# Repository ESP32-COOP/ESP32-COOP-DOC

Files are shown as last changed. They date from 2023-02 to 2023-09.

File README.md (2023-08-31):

<div align="center">
logo JS-BLE-DOC

# [ :book: ESP32 Coop Door Documentation ](https://coop-door.vercel.app/) 

The goal is to document the setup & configuration of the [esp32-coop](https://github.com/ESP32-COOP) project as well as the protocol in which the two devices communicate over BLE 
</div>

# :memo: Summary:

- [:page_facing_up: **Project Overview**](page_facing_up-project-overview): quick presentation of the mother project (goal, link device, protocol used, problematic) 
- [:iphone: **The App**](#iphone-app-installation): how to get the it
- [:toolbox: **Build instruction**](#toolbox-build-instruction)
   - :clipboard: Requirement
   - :flashlight: Wiring
   - :rocket: First Boot
   - :house: 3D file 
- :signal_strength: **Communication protocol**
   - :electric_plug: Run-down on how BLE works 
   - :bar_chart: The type of data required by the project (in progress) 
   - :computer: Code snippet for each characteristic (in progress)

# :page_facing_up: Project Overview

plan

The [COOP-DOOR](https://github.com/ESP32-COOP) project aims to create an intelligent and user-friendly automatic coop door system. It empowers users to customize the door's behavior based on specific conditions, such as time and light levels. To facilitate device management and monitoring, the project offers a mobile app. 

The app enables users to track device and sensor health, as well as configure various operating conditions. For a demonstration of the project, please refer to the demo [here](https://github.com/ESP32-COOP/ESP32-COOP-DOOR-WEB). The core of the smart coop door relies on the ESP-32 platform, and the code repository can be found [here](https://github.com/ESP32-COOP/ESP32-COOP-DOOR-CORE). 

This documentation page aims to guide users through the setup process, hardware requirements, and detailed workings of the system.

<br clear="left"/>

# :iphone: App Installation

app icon
<br clear="right"/>
The coop door application is a Progressive Web App, meaning it functions as a website and can be installed on mobile devices for offline usage.
<br clear="left"/>
<br clear="left"/>

To install the app, follow these steps:

1. Visit [coop-door.vercel.app](https://coop-door.vercel.app) using your mobile device's web browser.
2. A small popup will prompt you to install the app. Tap "Install" to proceed.
3. Alternatively, if the popup doesn't appear, you can manually add the app to your home screen by:
   - Tapping the three dots in Chrome.
   - Scrolling down and selecting "Add shortcut to home screen" or "Install app."
4. The app will be installed on your device and accessible from the home screen.

Now, you can conveniently use the mobile app to monitor and control your coop door system, even without an internet connection.

# :toolbox: Build instruction

Look out for instruction variations depending on the version of the project you're building.

First of all, you will need to flash the firmware on the ESP32. Please refer to the instructions [here](https://github.com/ESP32-COOP/ESP32-COOP-DOOR-CORE). I do recommend unplugging the motor before flashing the firmware to avoid any connection problems caused by the encoder or any accidental movement of the powered motor.

## :clipboard: Requirement

This projet use :<br>
- a ESP32 [WEMOS lolin32 lite](https://fr.aliexpress.com/item/4000038780903.html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) ( can be any esp32 with BLE), <br>
- a H-Bridge [l298n](https://fr.aliexpress.com/item/1005004510885871.html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),<br> 
- a [motor with a encoder](https://fr.aliexpress.com/item/4001314473291.html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), <br>
- and a [photoresistor](Vhttps://fr.aliexpress.com/item/32760631393.html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)

Additionally, you'll need some basic items such as wires, soldering equipment (or soldering iron), and a 3D printer or woodworking tools, depending on your preferences.

Please note that you can easily swap out any component of this project for a similar one. It will most likely work out fine, but it may require some extra work. I would recommend it only to experienced thinkers.

## :electric_plug: Wiring
As illustrated below, follow these connections:

ESP32:
- Connect encoder signal to pin 2 (yellow) and pin 15 (green).
- Attach a resistor to pin 34 for analog value.
- Control the H-bridge with pins 27 (ENA), 26 (IN1), and 15 (IN2).

Remember to establish a ground connection between the H-bridge and the ESP32.

wiring diagram

## :rocket: Initial Setup

**Before Coop Installation:**

It's a good idea to run comprehensive tests before installing the device in the coop. Debugging is much easier and less frustrating when you're comfortably situated in a well-ventilated room.

**Initial ESP32 Boot:**

When the ESP32 boots up initially, it assumes the door is closed. If that's not the case, unplug either the motor or the ESP and manually close the door.

**Proper Device Boot:**

Now you can properly start up your device. Inside the app, go to settings and then to the door section. Set the number of rotations you want the motor to perform in order to open the door. Click the test button, and the motor will complete a full cycle (going up and then back down). Begin with a small rotation number, and gradually adjust it until you reach your desired door height.

**Optimal Rotation Value:**

Once you've figured out the best number of motor rotations, jot down this value along with the light sensor reading. To sync the ESP32's time, head to the app's home page and click on the time badge. A panel will appear, showing the time difference between your phone and the ESP32, along with a sync button.

**Setting Conditions:**

With that sorted, configure open and closing conditions in the door settings. Base these conditions solely on time, and set the door to stay open for the rest of the day.

**Chicken Entry Time:**

Return to the coop at the designated chicken entry time to check the light sensor value. If needed, adjust the closing condition within the app's settings.

**Autonomous Operation:**

To enable autonomous operation, revisit the settings and door page. Click on 'auto' and then 'apply'.

## :carpentry_saw: Casing Details

You can find the 3D model at this [link](https://github.com/ESP32-COOP/JS-BLE-DOC/blob/main/3D_file_esp32_coop.stl), and the technical drawing is available //todo.

# :signal_strength: Wireless comunication
## :loudspeaker: BLE Protocol

BLE illustration
<br clear="right"/>
To better understand the following, you must understand the basics of the Bluetooth Low Energy (BLE) protocol.<br/>
The key part to understand is that it uses a fixed-size array of bytes to send data to an endpoint.
<br clear="left"/>
<br clear="left"/>

Each endpoint can have three properties: writable, readable, and notifyable.

- Writable: It allows the external user to write/edit the endpoint (officially called characteristic in BLE).
- Readable: It allows reading the characteristic's value.
- Notifyable: It allows getting notified when that value is updated.

A byte is made out of 8 bits, and its value can go from 0 to 255.

To send the desired value in bytes, you must think it through:

- You will need to figure out the array size you will need and the function to convert it back and forth in C and in JS.

Currently, there are five communication subjects:
1. The light sensor (made out of 4 bytes).
2. The time (made out of 9 bytes, 8 to represent UNIX time and 1 to represent the UTC offset).
3. The closing condition
4. The opening condition
5. Door settings

## :bulb: Data size

With BLE the goal is to send the smallest array posible

for each communication subjects i will justify each bytes and explain it's encoding

1. **The light sensor** produces 4 bytes of data. Our objective is to transmit the current value, along with the minimum and maximum values recorded by the sensor. To achieve this, we need an additional variable called a "divider." The maximum sensor value is fixed at 1024, while the highest value representable by a byte is 255.

   Calculating the divider is straightforward: we divide the maximum sensor value of 1024 by 255. This gives us the scaling factor needed for our encoding.

   With the divider in hand, we can create an encoded transmission as follows:
   - Current Value: current_value / divider
   - Minimum Value: min_value / divider
   - Maximum Value: max_value / divider
   - Unused Placeholder: (for the divider value)

   Reverting back to the original values is easy: simply multiply by the divider. This process maintains the integrity of the data throughout the encoding and decoding stages.
2. **The time** use 9 bytes The initial 8 bytes encode the UNIX time, while the ninth byte stores the user's country time offset.
   
   **Encoding UNIX Time**:
   To encode the UNIX time:
   - Begin by taking the lowest 8 bits of the time value using a bitwise AND operation with 0xff.
   - Place this extracted value in the current byte of the array.
   - Divide the time value by 256 to discard the lowest 8 bits for the next step.
   
   **Decoding UNIX Time**:
   To decode the UNIX time:
   - Set up a variable to hold the decoded time value.
   - Iterate eight times (for each byte), starting from the most significant byte down to the least:
       - Multiply the current result by 256 (shift left by 8 bits) to make room for the next byte.
       - Add the value of the current byte to the result.
   
   **Encoding Time Offset**:
   Encoding the time offset is simple. You subtract the time offset from 12 and then add back 12 during decoding. This process is necessary because the time offset ranges from -12 to 12.

3. **Door Condition** use 4 bytes, used by both open condtion and closing condtion.
      We ne the following value: the door mode (checking for light or time), the threshold and finaly the time
      The array is form like this [door_mode, light_treshold / 4, time hour, time minutes]
      The door mode is represented by a single digit, reflecting various modes:
      - 0 : do nothing
      - 1 : change on light condition
      - 2 : change on time condition
      - 3 : change on light and time condition
      - 4 : change on light or time condition
   By adopting this array format and the corresponding door modes, we efficiently handle door conditions during both opening and closing situations.
4. **Door settings** use 2 bytes, with the following needed value the door mode and the number of turn.
   
   The door mode can take on various values:
   - 0: Door closed
   - 1: Door open
   - 2: Test door (opens and closes immediately)
   - 10: Automatic mode with the door closed
   - 11: Automatic mode with the door open
   
   **Number of Turns Encoding**:
   To encode the number of turns, we simply multiply the value by 10.
   
   Here's the array structure for encoding: [door_mode, number_of_turns * 10].

## :gear: Code Snippette
Certainly, here's your code snippet presented in a more readable manner:

## Encoding and Decoding Long Numbers to Bytes

Here, we present functions for encoding and decoding long numbers into bytes. These functions are particularly relevant for working with the UNIX time standard. We provide the code snippets for both C and JavaScript:

### C Implementation

```c
byte* getBytesFromLong(long x) {
  byte* bytes = new byte[8];
  for (int i = 0; i < 8; i++) {
    bytes[i] = x & 0xff;
    x = (x - bytes[i]) / 256;
  }
  return bytes;
}

long getLongFromBytes(const byte* bytes) {
  long result = 0;
  for (int i = 7; i >= 0; i--) {
    result = (result * 256) + bytes[i];
  }
  return result;
}
```

### JavaScript Implementation

```javascript
export function getLongFromBytesBuffer(bytes) {
  let result = 0;
  for (let i = 7; i >= 0; i--) {
    result = result * 256 + bytes.getUint8(i);
  }
  return result;
}

export function getArrayFromBuffer(bytes, len) {
  let result = [];
  for (let i = 0; i < len; i++) {
    result.push(bytes.getUint8(i));
  }
  return result;
}
```

These functions offer efficient ways to convert long numbers to byte arrays and vice versa, which is particularly useful for working with the UNIX time standard. The C and JavaScript implementations cater to different programming environments, ensuring flexibility in usage.

## Tutorial
Here is a video that explain how the BLE work
//todo
Communication between JS and an ESP32

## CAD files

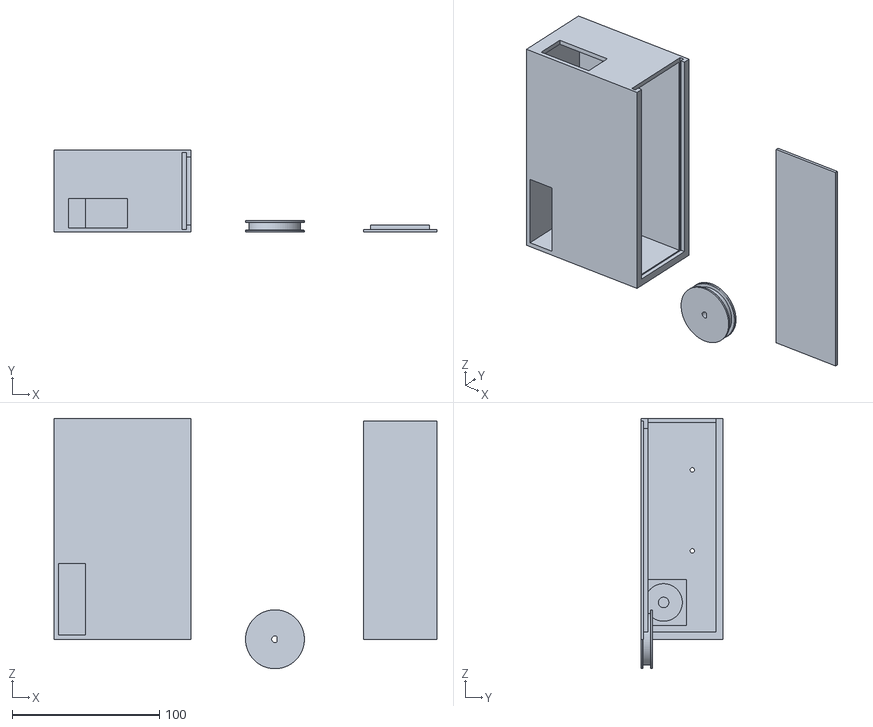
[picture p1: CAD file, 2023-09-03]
3D_file_esp32_coop.Stl
260.0 x 56.0 x 170.0

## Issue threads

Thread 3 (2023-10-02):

Add doc step by step illustration

Qypol342, 2023-10-02:
### Description:
The current documentation for this project is comprehensive but could benefit from step-by-step illustrations to enhance user-friendliness. We need to include the following illustrations to guide users effectively:

### Steps:

-  Set the door to the closed position.
- Power/plug in the device.
-  Open the app on your phone.
-  Finally, upload your settings.

### Illustrations Style:

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

### Comments:
You can request access to the Figma project by commenting on this issue.

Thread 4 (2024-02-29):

Esp32 ble

Peteroooooo, 2024-02-29:
I can't get the esp32 to turn on ble.
What do I exactly have to install on it?

raleighvanepps, 2024-03-09:
if your esp32 is turning on but it's not broadcasting bluetooth, make sure you've flashed it correctly and are supply sufficient voltage. If the input voltage isn't high enough the esp light will turn on but it won't work correctly.

Peteroooooo, 2024-03-12:
I checken

> if your esp32 is turning on but it's not broadcasting bluetooth, make sure you've flashed it correctly and are supply sufficient voltage. If the input voltage isn't high enough the esp light will turn on but it won't work correctly.

I checked the voltage and it seems to be ok.
Is it possible that I load the wrong firmware?

loan-mgt, 2025-03-03:
Flash it again, and you would be certain (could also be a defective exp32).

Open back up the issue if it persists

Closed 2025-03-03.

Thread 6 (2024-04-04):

Motor Control Issue

helidave, 2024-04-04:
Hi.  Firstly thank you for posting this project.
I do not currently have a motor with embedded encoder but I can connect the encoder I do have to the motor shaft and read the rotation.  However when I try to operate the motor from the app it does try to turn the motor (maybe 1/10th of a turn) and always in the same direction.   I do not see a change in encoder value when I look at the ESP serial output.
Any pointers as to what I am doing incorrectly?
Thanks,
David

helidave, 2024-04-07:
please close above thread. I worked out what my problem was. I needed pull up resistors on the signal lines of my encoder.

JohnMcLear, 2024-06-08:
@helidave you can close this yourself.

Closed 2025-03-03.

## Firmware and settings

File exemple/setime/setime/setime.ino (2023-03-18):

#include <ArduinoBLE.h>
#include <ESP32Time.h>

ESP32Time rtc;
//ESP32Time rtc(3600);  // offset in seconds GMT+1

BLEService service("1ce76320-2d32-41af-b4c4-46836ea7a62a"); // Bluetooth® Low Energy LED Service
BLECharacteristic dateCharacteristic("ad804469-19ec-406a-b949-31ae17e43813", BLERead | BLENotify | BLEWrite, 8);
BLECharacteristic lightCharacteristic("947aad02-c25d-11ed-afa1-0242ac120002", BLERead | BLENotify | BLEWrite , 4);
BLECharacteristic doorCharacteristic("c3773399-b755-4e30-9160-bed203fae718", BLERead | BLENotify | BLEWrite , 2);
BLECharacteristic doorCloseCharacteristic("e011ba0e-84c5-4e83-8648-f3e2660c44b0", BLERead | BLENotify | BLEWrite , 4);
BLECharacteristic doorOpenCharacteristic("cc959fff-4f84-4d08-a720-9d9156a48ed5", BLERead | BLENotify | BLEWrite , 4);

//badge
uint8_t ble_value = 0x0;
int analogValue = 500;
int minValue = analogValue; 
int maxValue = analogValue; 

//settings door
int doorWantedStatus = 0;
int doorNbTurn = 1;

//settings close
int doorCloseMode = 0;
int doorCloseLightThreshold = -1;
int doorCloseTimeH = -1;
int doorCloseTImeM = -1;

//settings open
int doorOpenMode = 0;
int doorOpenLightThreshold = -1;
int doorOpenTimeH = -1;
int doorOpenTImeM = -1;


void setup() {
  Serial.begin(9600);
  rtc.setTime(1609459200);
  while (!Serial);

  // begin initialization
  if (!BLE.begin()) {
    Serial.println("starting Bluetooth® Low Energy module failed!");
    while (1);
  }

  // set advertised local name and service UUID:
  BLE.setLocalName("COOP-DOOR");
  BLE.setAdvertisedService(service);
  service.addCharacteristic(dateCharacteristic);
  service.addCharacteristic(lightCharacteristic);
  service.addCharacteristic(doorCharacteristic);
  service.addCharacteristic(doorCloseCharacteristic);
  service.addCharacteristic(doorOpenCharacteristic);
  BLE.addService(service);
  dateCharacteristic.writeValue(0);
  lightCharacteristic.writeValue(0);
  doorCharacteristic.writeValue(0);


  // start advertising
  BLE.advertise();

  Serial.println("BLE LED Peripheral");
}

void loop() {
  // listen for Bluetooth® Low Energy peripherals to connect:
  BLEDevice central = BLE.central();

  // if a central is connected to peripheral:
  if (central) {
    Serial.print("Connected to central: ");
    // print the central's MAC address:
    Serial.println(central.address());

    // while the central is still connected to peripheral:
    while (central.connected()) {
      // if the remote device wrote to the characteristic,
      // use the value to control the LED:
      delay(500);

      manageDate();
      manageLight();
      manageSettingsDoor();
      manageSettingsClose();
      manageSettingsOpen();



    }

    // when the central disconnects, print it out:
    Serial.print(F("Disconnected from central: "));
    Serial.println(central.address());
  }





}

void manageSettingsOpen(){
  if (doorOpenCharacteristic.written() ) {
    Serial.println("update Door Open settings");
    Serial.print(doorOpenCharacteristic.value()[0]);
    Serial.print(";");
    Serial.print(doorOpenCharacteristic.value()[1]);
    Serial.print(";");
    Serial.print(doorOpenCharacteristic.value()[2]);
    Serial.print(";");
    Serial.println(doorOpenCharacteristic.value()[3]);
    doorOpenMode = doorOpenCharacteristic.value()[0];
    doorOpenLightThreshold = doorOpenCharacteristic.value()[1];
    doorOpenTimeH = doorOpenCharacteristic.value()[2];
    doorOpenTImeM = doorOpenCharacteristic.value()[3];
    
  }else{
    //todo
  }
}

void manageSettingsClose(){
  if (doorCloseCharacteristic.written() ) {
    Serial.println("update Door Close settings");
    Serial.print(doorCloseCharacteristic.value()[0]);
    Serial.print(";");
    Serial.print(doorCloseCharacteristic.value()[1]);
    Serial.print(";");
    Serial.print(doorCloseCharacteristic.value()[2]);
    Serial.print(";");
    Serial.println(doorCloseCharacteristic.value()[3]);
    doorCloseMode = doorCloseCharacteristic.value()[0];
    doorCloseLightThreshold = doorCloseCharacteristic.value()[1];
    doorCloseTimeH = doorCloseCharacteristic.value()[2];
    doorCloseTImeM = doorCloseCharacteristic.value()[3];
    
  }else{
    //todo
  }
}


void manageSettingsDoor(){
  if (doorCharacteristic.written() ) {
    Serial.println("update Door");
    Serial.print(doorCharacteristic.value()[0]);
     Serial.print(";");
      Serial.println(doorCharacteristic.value()[1]);
  }else{
    //todo
  }
}

void manageLight(){
  if (lightCharacteristic.written() && lightCharacteristic.value()[3] != 0x00) {
    analogValue = random(10, 1000);
    minValue = analogValue;
    maxValue = analogValue;
    Serial.println("reset light");

    
  } else {
    analogValue = random(10, 1000);
    minValue = min(analogValue, minValue);
    maxValue = max(analogValue, maxValue);
  }
  Serial.print(" value ");
  Serial.print(analogValue);
  Serial.print(" minValue ");
  Serial.print(minValue);
  Serial.print(" maxValue ");
  Serial.print(maxValue);
  Serial.println("");
  float divider = 1000 / 255.0; //1000 max allowed value, 255 max byte value
  uint8_t currentValue = analogValue / divider;
  uint8_t scaledMinValue = minValue / divider;
  uint8_t scaledMaxValue = maxValue / divider;

  uint8_t ble_value_array[4] = {currentValue, scaledMinValue, scaledMaxValue, 0x00 };

  // Write the array to the characteristic
  lightCharacteristic.writeValue(ble_value_array, 4);
  
  
}





void manageDate() {
  if (dateCharacteristic.written()) {
    Serial.println("Date update");
    long xx = getLongFromBytes(dateCharacteristic.value());
    Serial.println(xx);
    rtc.setTime(xx);
    Serial.println(rtc.getEpoch());


  } else {
    Serial.println(rtc.getEpoch());
    byte* tmpDate = getBytesFromLong(rtc.getEpoch());

    dateCharacteristic.writeValue(tmpDate, 8);
    delete[] tmpDate;
  }

}


byte* getBytesFromLong(long x  ) {
  byte* bytes = new byte[8];
  for (int i = 0; i < 8; i++) {
    bytes[i] = x & 0xff;
    x = (x - bytes[i]) / 256;
  }
  return bytes;

}

long getLongFromBytes(const byte* bytes) {
  long result = 0;
  for (int i = 7; i >= 0; i--) {
    result = (result * 256) + bytes[i];
  }
  return result;
}

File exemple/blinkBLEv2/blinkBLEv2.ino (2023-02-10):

 #include <ArduinoBLE.h>

BLEService ledService("19B10000-E8F2-537E-4F6C-D104768A1214"); // Bluetooth® Low Energy LED Service

// Bluetooth® Low Energy LED Switch Characteristic - custom 128-bit UUID, read and writable by central
BLEByteCharacteristic switchCharacteristic("19B10001-E8F2-537E-4F6C-D104768A1214", BLERead | BLEWrite);
BLEByteCharacteristic switchCharacteristic2("77a57c66-3bc9-463a-bc52-1ee5763b9c0f", BLERead | BLENotify);

BLEService dateService("1ce76320-2d32-41af-b4c4-46836ea7a62a"); // Bluetooth® Low Energy LED Service
BLECharacteristic dateCharacteristic("ad804469-19ec-406a-b949-31ae17e43813", BLERead | BLENotify | BLEWrite,5);

const int ledPin = LED_BUILTIN; // pin to use for the LED
uint8_t ble_value = 0x0;

void setup() {
  Serial.begin(9600);
  while (!Serial);

  // set LED pin to output mode
  pinMode(ledPin, OUTPUT);

  // begin initialization
  if (!BLE.begin()) {
    Serial.println("starting Bluetooth® Low Energy module failed!");

    while (1);
  }

  // set advertised local name and service UUID:
  BLE.setLocalName("COOP-DOOR");
  BLE.setAdvertisedService(ledService);
  BLE.setAdvertisedService(dateService);

  // add the characteristic to the service
  ledService.addCharacteristic(switchCharacteristic);
  ledService.addCharacteristic(switchCharacteristic2);
  
  dateService.addCharacteristic(dateCharacteristic);

  // add service
  BLE.addService(ledService);

  BLE.addService(dateService);

  // set the initial value for the characeristic:
  switchCharacteristic.writeValue(0);
  switchCharacteristic2.writeValue(0);

  dateCharacteristic.writeValue(0);

  // start advertising
  BLE.advertise();

  Serial.println("BLE LED Peripheral");
}

void loop() {
  // listen for Bluetooth® Low Energy peripherals to connect:
  BLEDevice central = BLE.central();

  // if a central is connected to peripheral:
  if (central) {
    Serial.print("Connected to central: ");
    // print the central's MAC address:
    Serial.println(central.address());

    // while the central is still connected to peripheral:
    while (central.connected()) {
      // if the remote device wrote to the characteristic,
      // use the value to control the LED:
      
      if (switchCharacteristic.written()) {
         Serial.println("update");
        if (switchCharacteristic.value()) {   // any value other than 0
          Serial.println("LED on");
          digitalWrite(ledPin, HIGH);         // will turn the LED on
        } else {                              // a 0 value
          Serial.println("LED off");
          digitalWrite(ledPin, LOW);          // will turn the LED off
        }
      }

      if (dateCharacteristic.written()){
        Serial.println("Date update");
         Serial.println(dateCharacteristic.value()[0]);
         Serial.println(dateCharacteristic.value()[1]);
         Serial.println(dateCharacteristic.value()[2]);
         Serial.println(dateCharacteristic.value()[3]);
         Serial.println(dateCharacteristic.value()[4]);
      }
        ble_value = random(0, 11);
        switchCharacteristic2.writeValue(ble_value);
    }

    // when the central disconnects, print it out:
    Serial.print(F("Disconnected from central: "));
    Serial.println(central.address());
  }

  
  
  
}

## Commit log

2023-02-11 feat(home): gear button
2023-02-11 feat(home): add icon and better button
2023-02-14 feat(light-sensor): add min max and value
2023-02-15 fix(light-sensor): grid layout
2023-03-15 add reset light support
    [setime.ino]
2023-03-15 add support for reset for light
    [setime.ino]
2023-08-22 add 3D file
    [3D_file_esp32_coop.stl]
2023-09-03 update 3D model
    [3D_file_esp32_coop.Stl, 3D_file_esp32_coop.stl]
